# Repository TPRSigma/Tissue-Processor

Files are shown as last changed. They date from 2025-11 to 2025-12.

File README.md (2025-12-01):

# Tissue-Processor
Simple Tissue Processor for fixation and contrasting of samples for **light and electron microscopy**. 

Úvodní obr

This repository contains the documentation, control files, and construction details for a custom-built **automated tissue processor** designed for preparing biological samples for **light and electron microscopy**.  
The device automates sequential immersion of samples into up to **20 reagent baths**, following a user-defined protocol stored on an SD card.

---

## Key Features

- **Fully automated sample immersion** into up to 20 baths  
- **Compatible with Leica EM CPD300 baskets** (up to 4 baskets per run)  
- **Motorized carousel + lift** controlled by an onboard microcontroller  
- **e-mail notifications** (status, errors, power outage alerts)  
- **Backup battery** to complete the ongoing immersion step  
- **Simple protocol definition** via text file (`proto_NN.txt`) on SD card  
- **Manual control mode** for lift and carousel  
- **Intuitive front-panel interface** with MENU/ENTER buttons and rotary knob

---

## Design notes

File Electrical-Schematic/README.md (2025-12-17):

# Electrical Schematic – Tissue Processor

This directory contains the electrical schematics of the **Tissue Processor** device,
showing the interconnection of all electronic components.

The schematics document:
- power distribution and voltage regulation  
- microcontroller connections  
- motor drivers and actuators  
- sensors and limit switches  
- display, control panel, and user inputs  
- communication interfaces (Bluetooth, I²C, SPI)  

---

## 🖼️ Schematic Overview

<p align="center">
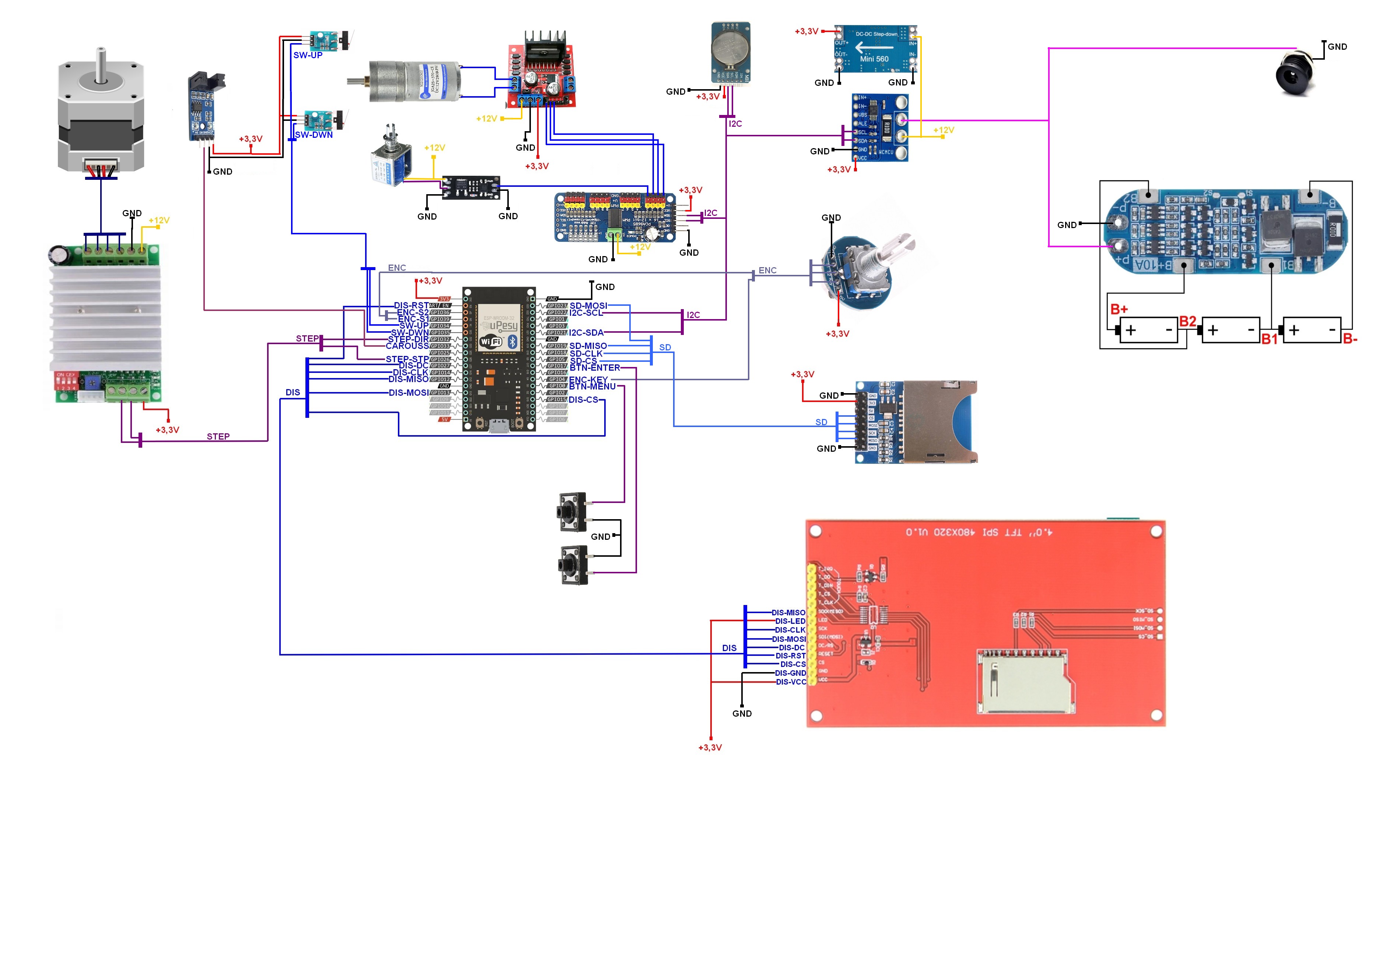
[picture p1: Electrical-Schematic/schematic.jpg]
Tissue Processor Electrical Schematic
  
</p>

---

The diagram provides an overview of the system architecture and wiring between
individual modules. It is intended as a reference for maintenance, debugging,
and further development.

> **Note:** Component values, pin assignments, and wiring correspond to the hardware
revision used in this project. Hardware changes may require schematic updates.

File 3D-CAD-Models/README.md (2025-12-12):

# 3D CAD Models
This directory contains **3D CAD models** of individual parts of the Tissue Processor in **STL** format as well as the entire assembly **TP-assembly** in **IGES** and **STEP** formats.
<br>
<p align="center">TP-assembly</p>

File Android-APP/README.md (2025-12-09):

# TP Control v1.0 – Android App for Tissue Processor

<p align="center">

</p>
<sup> © 2025 Jane Doe – Released under the MIT License.</sup>

<br>
<br>
    
This directory contains the Android application **TP Control**, which communicates 
with the Tissue Processor device via Bluetooth.

The app provides a user-friendly interface for:

- Connecting to the Tissue Processor via Bluetooth  
- Configuring device settings  
- Creating and editing tissue-processing protocols

---
## 📦 Structure
```
/Android-APP
│
├── build/ # Compiled APK
└── README.md
```
<!-- ├── app/ # Android Studio project -->
---

## 📲 Installing an APK on Android (build)

This guide explains how to install an Android application directly from an `.apk` file, without using the Google Play Store.

---

### 1. Enable Installation from Unknown Sources

1. Open **Settings** on your Android device.
2. Go to **Apps** or **Apps & notifications**.
3. Find **Special app access** or **Install unknown apps**.
4. Select the app you will use to install the APK (e.g., **Browser** or **File Manager**).
5. Enable **Allow from this source**.

> ⚠️ Warning: Installing apps from unknown sources can be a security risk. Only install trusted APKs.

---

### 2. Transfer the APK to Your Device

- Move the `.apk` file to your device via USB, email, cloud storage, or Bluetooth.
- Recommended location: **Downloads** folder or a folder you commonly use for files.

---

### 3. Open the APK File

1. Open a **File Manager** or **Downloads** app on your device.
2. Locate the `.apk` file you want to install.
3. Tap the file and confirm the installation.

---

### 4. Complete Installation

- Follow the installer prompts.
- Once finished, you can open the app directly or find it on your home screen.

---

### 5. Tips

- If the installation fails, make sure the `.apk` file is not corrupted and is compatible with your Android version.
- After installation, consider disabling **installation from unknown sources** for security.
---

### 6. Pair the app with the Tissue Processor over Bluetooth.
> **Note:** The app requires Bluetooth permission on the Android device.
---
<!--
## 📲 Installing and Running APP

1. Open the project in **Android Studio**.  
2. Connect an Android device or emulator.  
3. Build and run the app.  
4. Pair the app with the Tissue Processor over Bluetooth.

> **Note:** The app requires Bluetooth permission on the Android device.

---
-->

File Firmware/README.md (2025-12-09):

# Firmware v22.a
<p align="center">

</p>
<sup>© 2025 Jane Doe – Released under the MIT License.</sup>
<br>
<br>
This directory contains the firmware used to control the Tissue Processor device.  
It includes:

- **Main Arduino project** (`tissue_processor.ino`)  
  The primary source code for the microcontroller.  
- **Precompiled firmware binaries** (in the `/bin` subfolder)  
  These files can be flashed directly onto the device without rebuilding the project.

The firmware controls all key functions of the device, including:
- carousel rotation  
- lift motion  
- protocol execution  
- SD card management  
- display and control panel interface  
- error reporting and network notifications
- Bluetooth interface for communication with the Android companion app, which provides a user-friendly way to configure the device and create tissue-processing protocols.

---

## 📦 Structure
```
/Firmware
│
├── Graficke_rozhrani_v22a.ino        # Arduino IDE project
│
└── bin/
    ├── Graficke_rozhrani_v22a.ino.bin
    ├── Graficke_rozhrani_v22a.ino.elf
    └── ...
```
---

## 🛠️ Flashing the Firmware

To upload the firmware:

1. Open the `.ino` file in **Arduino IDE** (or PlatformIO).  
2. Select the correct board and COM port.  
3. Click **Upload**.

Or, to flash the precompiled binary using `esptool.py`:

```bash
esptool.py --chip esp32 write_flash 0x10000 Graficke_rozhrani_v22a.ino.merged.bin

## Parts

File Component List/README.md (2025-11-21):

# Bill of Materials (BOM)

## Electronics

| Qty | Component | Link |
|-----|---|---|
| 1 | Processor (ESP-32S) | https://www.laskakit.cz/iot-esp-32s-2-4ghz-dual-mode-wifi-bluetooth-rev-1--cp2102/ |
| 1 | Display (ST7796) | https://www.laskakit.cz/4-0--480x320-tft-displej--st7796--spi--dotykovy/ |
| 1 | Balancer / Charger (3S) | https://www.laskakit.cz/ochrana-li-ion-baterie-3s-10a/ |
| 1 | Stepdown 3.3V | https://www.laskakit.cz/mini-smd-step-down-menic-3-3v/ |
| 3 | Battery 18650 | https://www.laskakit.cz/geb-li-ion-baterie-18650-2200mah-3-7v/ |
| 1 | Battery Case (3×18650) | https://www.laskakit.cz/bateriovy-box-3x18650-dratove-vyvody/ |
| 1 | Photoelectric Gate | https://www.laskakit.cz/fotoelektricky-snimac-otacek/ |
| 1 | Stepper Motor (NEMA17) | https://www.laskakit.cz/krokovy-motor-nema-17-17hs2408-0-12nm/ |
| 1 | Cable for Stepper | https://www.laskakit.cz/kabel-pro-krokovy-motor-nema17-s-konektorem-jst-xh-1m/ |
| 1 | Stepper Motor Driver (TB6600) | https://www.laskakit.cz/driver-tb6600-pro-krokove-motory-4a-9-42v-pcb/ |
| 1 | DC Motor – 150 RPM | https://www.laskakit.cz/motor-jga25-370-12v-s-prevodovkou-/ |
| 1 | DC Driver (L298N) | https://www.laskakit.cz/h-mustek-pro-krokovy-motor-l298n--dualni-motorovy-modul/ |
| 1 | I2C PWM Driver (PCA9685) | https://www.laskakit.cz/16-kanalovy-12-bit-pwm-servo-mini-shield-i2c-pca9685/ |
| 1 | RTC DS3231 | https://www.laskakit.cz/rtc-hodiny-realneho-casu-ds3231--integrovana-baterie/ |
| 1 | PWM Module for Electromagnet | https://www.laskakit.cz/pwm-mosfet-modul-lr7843--30vdc-161a/ |
| 2 | Momentary Switch + Button | https://www.laskakit.cz/mikrospinac-tc-1212t-12x12x7-3mm/ ; https://www.laskakit.cz/tlacitko-12x12x7-3mm-s-knoflikem/?variantId=5051 |
| 1 | Rotary Encoder | https://www.laskakit.cz/rotacni-encoder-s-tlacitkem-a-rc-s-filtrem/ |
| 1 | Power Connector DC 5.5×2.1mm | https://www.laskakit.cz/napajeci-konektor-dc-022-5-5-2-1mm-do-panelu/ |
| 1 | Voltmeter Module | https://www.laskakit.cz/laskakit-ina226-sensor-pro-mereni-napeti--proudu-a-vykonu/ |
| 1 | Cable JST-SH 6-pin | https://www.laskakit.cz/--sup-spi-jst-sh-6-pin-kabel-dupont-samec/ |
| 1 | SD Card Reader | https://www.laskakit.cz/sd-card-modul-spi/ |
| 1 | Switch | https://www.laskakit.cz/spinac-kovovy-s-aretaci-power--stribrny-16mm-3-6v/ |
| 1 | AC Power Adapter 12V 3A | https://www.laskakit.cz/sitovy-napajeci-adapter-12v-3a-5-5-2-1mm/ |

## Mechanics / Construction

| Qty | Component | Link |
|-----|---|---|
| 1 | Threaded Rod 200 mm | https://dratek.cz/arduino/148409-zavitova-tyc-trapezova-t8-8-p2-pravy-zavit-s-matici-200mm.html |
| 1 | Shaft Coupling 5×8 mm | https://dratek.cz/arduino/122878-hridelova-spojka-pruzna-cnc-5x8mm.html |
| 1 | Bearing KP08 | https://dratek.cz/arduino/122932-kp08-upinaci-lozisko-8mm-stojate.html |
| 1 | Guide Rod 8 mm / 200 mm | https://dratek.cz/arduino/148608-vodici-tyc-ocelova-chromovana-prumer-8-mm-delka-200-mm.html |
| 1 | Linear Ball Bearing SC8UU | https://dratek.cz/arduino/7780-linearni-vozik-sc8uu.html |
| 2 | Limit Switch | https://www.laskakit.cz/koncovy-doraz-spinac--2a-125vac/ |
| 1 | Electromagnet | https://www.laskakit.cz/elektromagnet-tazny--12v-10mm-20n/ |
| 1 | Carousel Bearing Ø200 mm | https://www.kovaninabytkove.cz/p/otocny-mechanismus-pro-talir-desku-pr-200mm-1 |
| 20  | Centrifugal Glass Tubes 25 ml (H095003)  | https://www.p-lab.cz/zkumavka-centrifugacni-s-kulatym-dnem |

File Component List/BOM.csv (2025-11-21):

Category | Qty | Component | Link
Electronics | 1 | Processor (ESP-32S) | https://www.laskakit.cz/iot-esp-32s-2-4ghz-dual-mode-wifi-bluetooth-rev-1--cp2102/
Electronics | 1 | Display (ST7796) | https://www.laskakit.cz/4-0--480x320-tft-displej--st7796--spi--dotykovy/
Electronics | 1 | Balancer / Charger (3S) | https://www.laskakit.cz/ochrana-li-ion-baterie-3s-10a/
Electronics | 1 | Stepdown 3.3V | https://www.laskakit.cz/mini-smd-step-down-menic-3-3v/
Electronics | 3 | Battery 18650 | https://www.laskakit.cz/geb-li-ion-baterie-18650-2200mah-3-7v/
Electronics | 1 | Battery Case (3×18650) | https://www.laskakit.cz/bateriovy-box-3x18650-dratove-vyvody/
Electronics | 1 | Photoelectric Gate | https://www.laskakit.cz/fotoelektricky-snimac-otacek/
Electronics | 1 | Stepper Motor (NEMA17) | https://www.laskakit.cz/krokovy-motor-nema-17-17hs2408-0-12nm/
Electronics | 1 | Cable for Stepper | https://www.laskakit.cz/kabel-pro-krokovy-motor-nema17-s-konektorem-jst-xh-1m/
Electronics | 1 | Stepper Motor Driver (TB6600) | https://www.laskakit.cz/driver-tb6600-pro-krokove-motory-4a-9-42v-pcb/
Electronics | 1 | DC Motor – 150 RPM | https://www.laskakit.cz/motor-jga25-370-12v-s-prevodovkou-/
Electronics | 1 | DC Driver (L298N) | https://www.laskakit.cz/h-mustek-pro-krokovy-motor-l298n--dualni-motorovy-modul/
Electronics | 1 | I2C PWM Driver (PCA9685) | https://www.laskakit.cz/16-kanalovy-12-bit-pwm-servo-mini-shield-i2c-pca9685/
Electronics | 1 | RTC DS3231 | https://www.laskakit.cz/rtc-hodiny-realneho-casu-ds3231--integrovana-baterie/
Electronics | 1 | PWM Module for Electromagnet | https://www.laskakit.cz/pwm-mosfet-modul-lr7843--30vdc-161a/
Electronics | 2 | Momentary Switch + Button | https://www.laskakit.cz/mikrospinac-tc-1212t-12x12x7-3mm/ ; https://www.laskakit.cz/tlacitko-12x12x7-3mm-s-knoflikem/?variantId=5051
Electronics | 1 | Rotary Encoder | https://www.laskakit.cz/rotacni-encoder-s-tlacitkem-a-rc-s-filtrem/
Electronics | 1 | Power Connector DC 5.5×2.1mm | https://www.laskakit.cz/napajeci-konektor-dc-022-5-5-2-1mm-do-panelu/
Electronics | 1 | Voltmeter Module | https://www.laskakit.cz/laskakit-ina226-sensor-pro-mereni-napeti--proudu-a-vykonu/
Electronics | 1 | Cable JST-SH 6-pin | https://www.laskakit.cz/--sup-spi-jst-sh-6-pin-kabel-dupont-samec/
Electronics | 1 | SD Card Reader | https://www.laskakit.cz/sd-card-modul-spi/
Electronics | 1 | Switch | https://www.laskakit.cz/spinac-kovovy-s-aretaci-power--stribrny-16mm-3-6v/
Electronics | 1 | AC Power Adapter 12V 3A | https://www.laskakit.cz/sitovy-napajeci-adapter-12v-3a-5-5-2-1mm/
Mechanics | 1 | Threaded Rod 200 mm | https://dratek.cz/arduino/148409-zavitova-tyc-trapezova-t8-8-p2-pravy-zavit-s-matici-200mm.html
Mechanics | 1 | Shaft Coupling 5×8 mm | https://dratek.cz/arduino/122878-hridelova-spojka-pruzna-cnc-5x8mm.html
Mechanics | 1 | Bearing KP08 | https://dratek.cz/arduino/122932-kp08-upinaci-lozisko-8mm-stojate.html
Mechanics | 1 | Guide Rod 8 mm / 200 mm | https://dratek.cz/arduino/148608-vodici-tyc-ocelova-chromovana-prumer-8-mm-delka-200-mm.html
Mechanics | 1 | Linear Ball Bearing SC8UU | https://dratek.cz/arduino/7780-linearni-vozik-sc8uu.html
Mechanics | 2 | Limit Switch | https://www.laskakit.cz/koncovy-doraz-spinac--2a-125vac/
Mechanics | 1 | Electromagnet | https://www.laskakit.cz/elektromagnet-tazny--12v-10mm-20n/
Mechanics | 1 | Carousel Bearing O200 mm | https://www.kovaninabytkove.cz/p/otocny-mechanismus-pro-talir-desku-pr-200mm-1
Mechanics | 20 | Centrifugal Glass Tubes 25 ml (H095003) | https://www.p-lab.cz/zkumavka-centrifugacni-s-kulatym-dnem

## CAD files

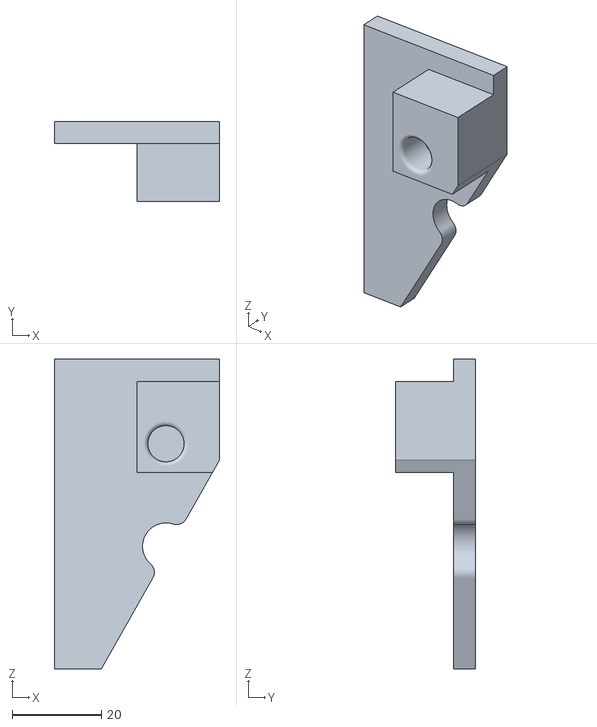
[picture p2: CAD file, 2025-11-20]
3D-CAD-Models/Rod Cover (Krytka tyče).stl
37.0 x 18.0 x 69.5

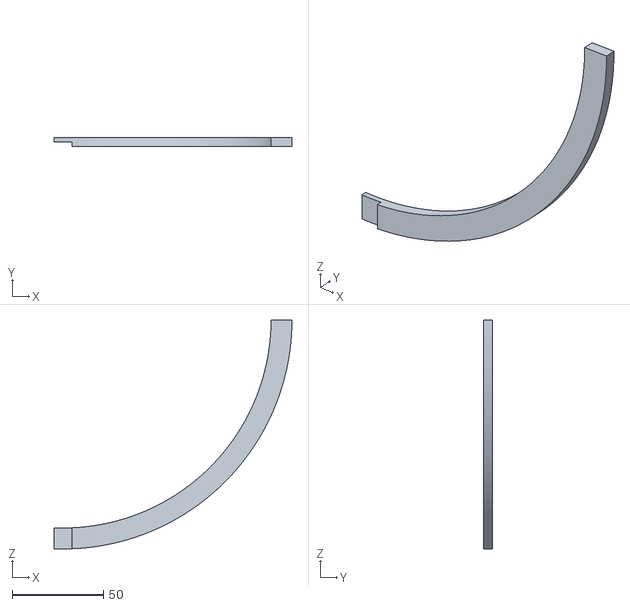
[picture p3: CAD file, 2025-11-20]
3D-CAD-Models/Top Back Plate 2 (Vrchni deska Zadní2).stl
130.6 x 5.00 x 125.6

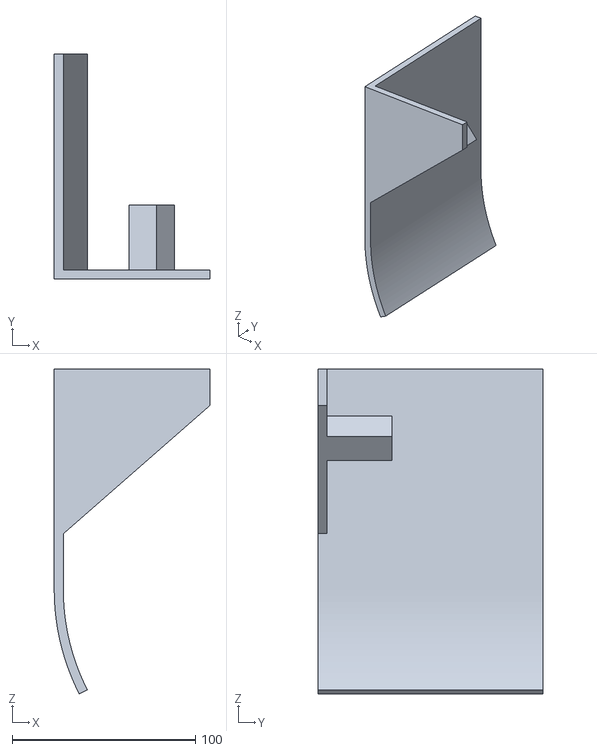
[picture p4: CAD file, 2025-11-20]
3D-CAD-Models/Right Panel 1 (Panel boční R_1).stl
85.0 x 123.0 x 177.6

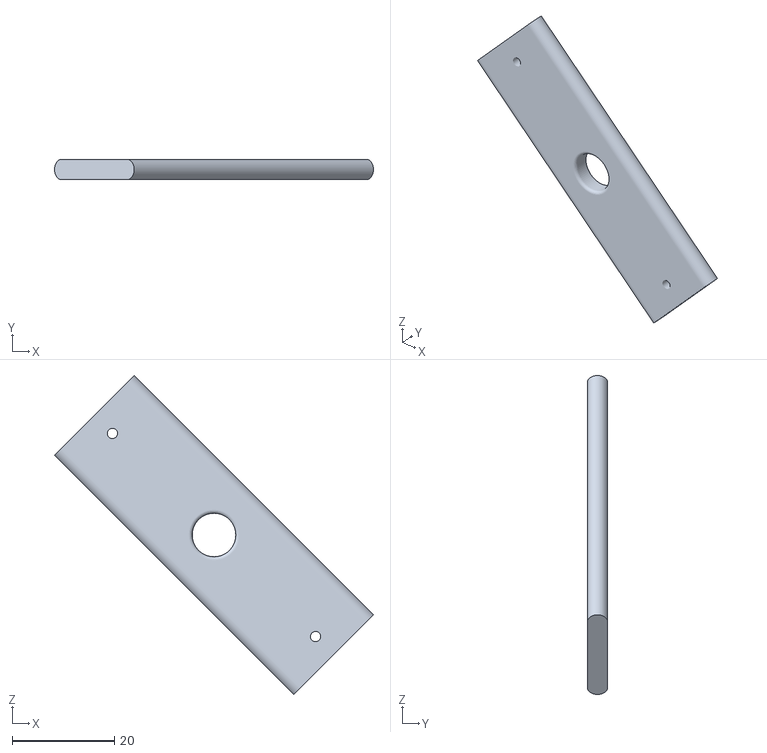
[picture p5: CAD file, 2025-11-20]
3D-CAD-Models/Sliding Bar (Posuvná lišta).stl
62.3 x 4.00 x 62.3

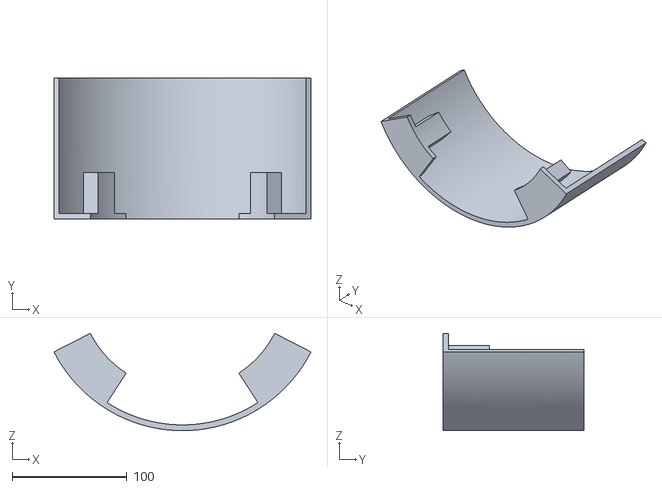
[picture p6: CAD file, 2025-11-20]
3D-CAD-Models/Rear Panel (Panel zadní).stl
223.7 x 123.0 x 84.7

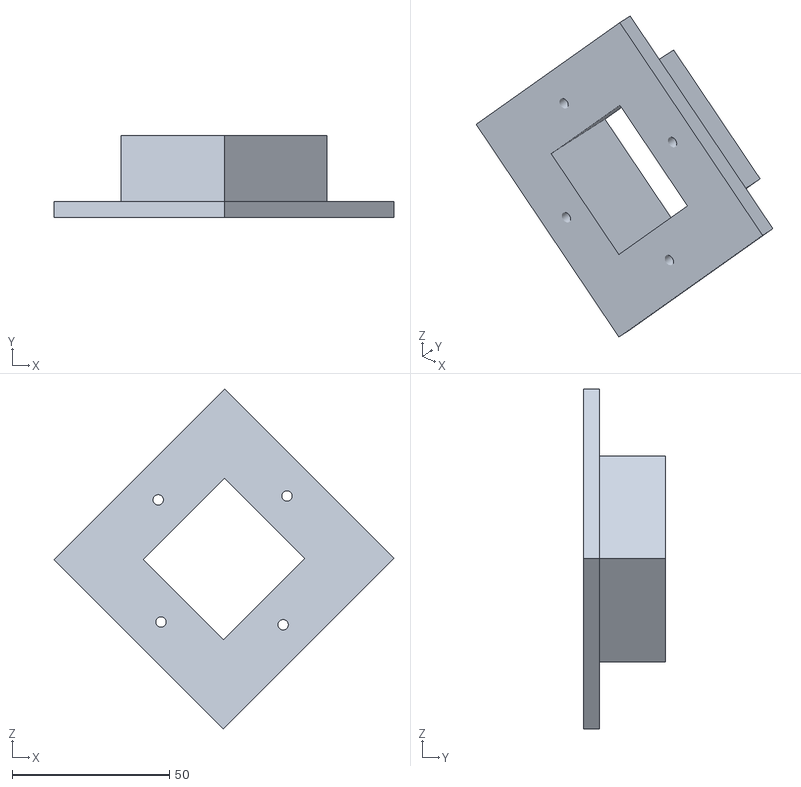
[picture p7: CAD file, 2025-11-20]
3D-CAD-Models/Lid Housing (Domeček víka).stl
108.0 x 26.0 x 108.0

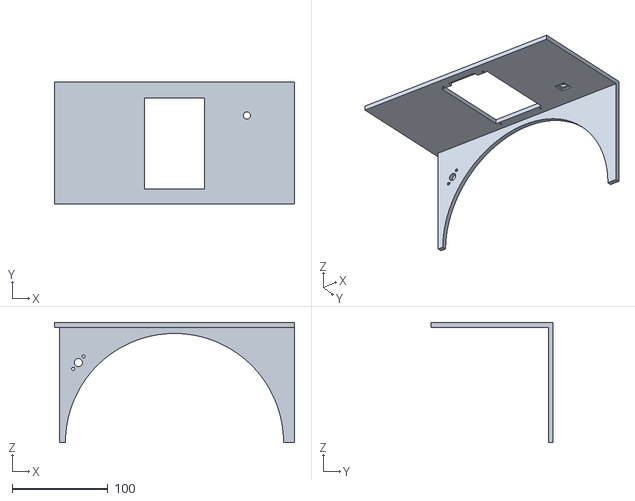
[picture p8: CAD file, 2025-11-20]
3D-CAD-Models/Front Panel (Panel přední).stl
251.1 x 128.0 x 125.6

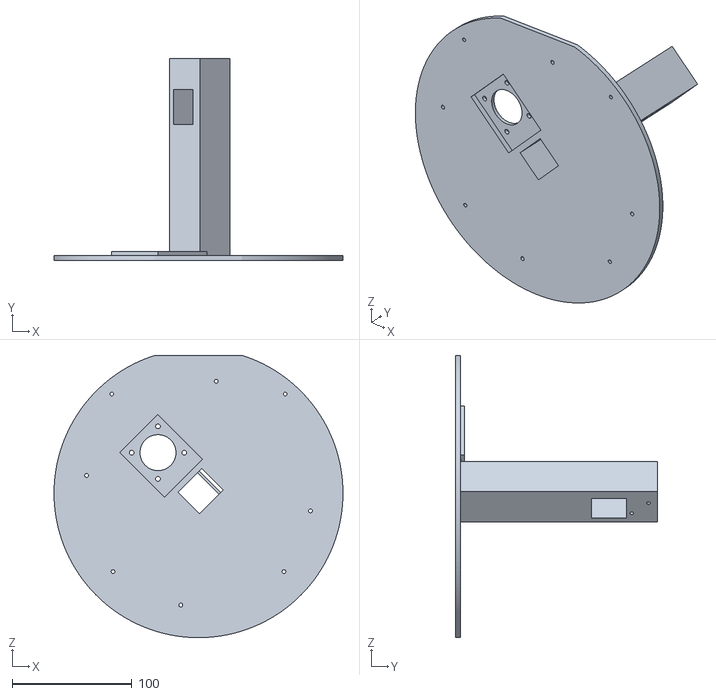
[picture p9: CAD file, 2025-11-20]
3D-CAD-Models/Base (Podstavec).stl
241.1 x 168.5 x 235.5

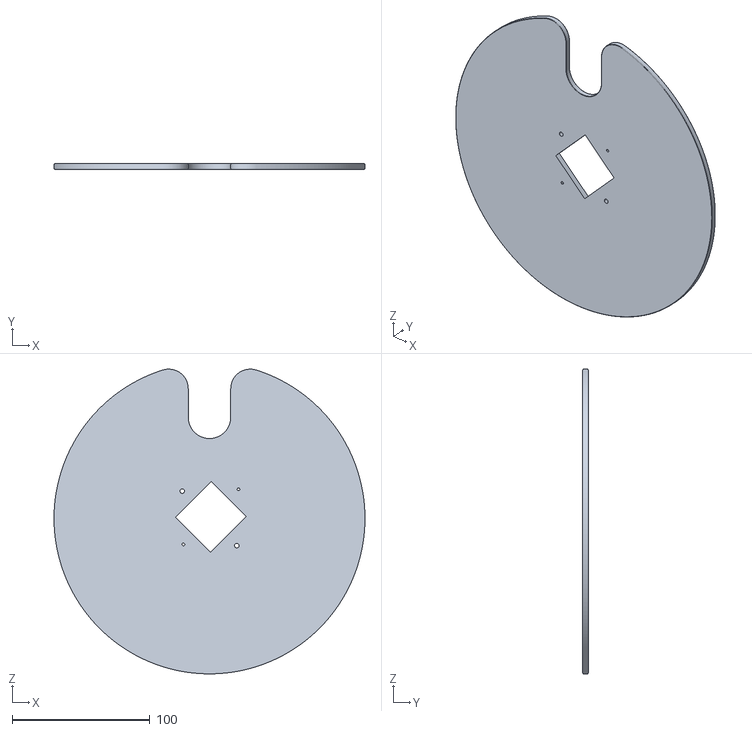
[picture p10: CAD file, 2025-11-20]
3D-CAD-Models/Lid (Víko).stl
226.1 x 4.00 x 221.6

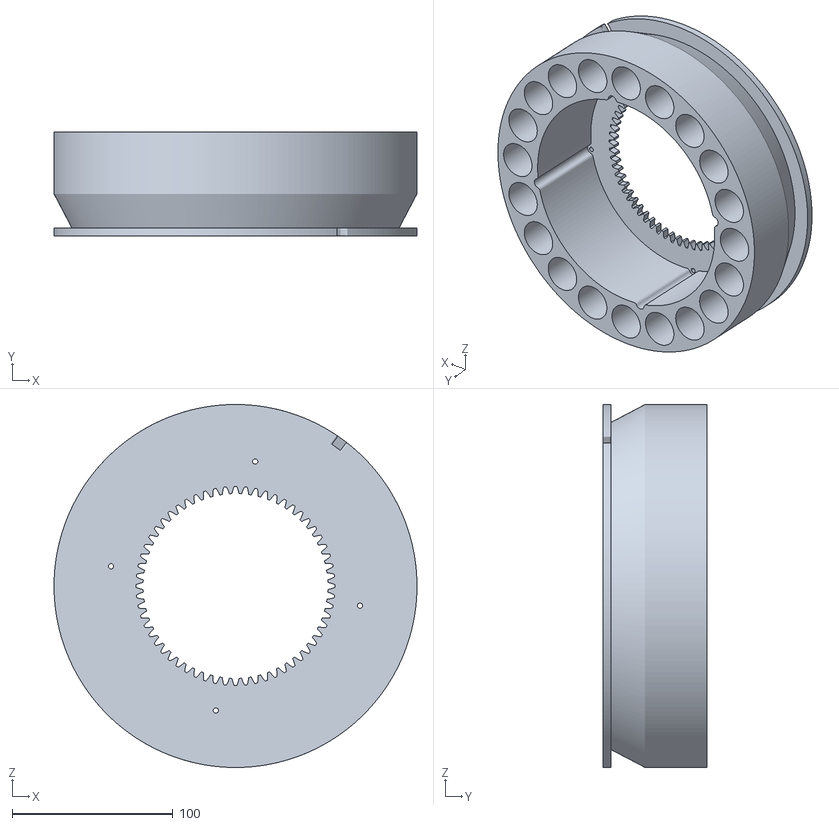
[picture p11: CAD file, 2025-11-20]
3D-CAD-Models/Carousel (Karusel).stl
226.1 x 65.0 x 226.1

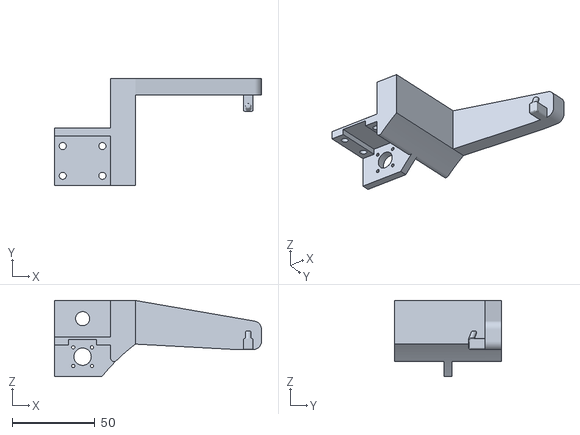
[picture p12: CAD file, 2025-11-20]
3D-CAD-Models/Holder (Držák).stl
125.3 x 65.0 x 46.0

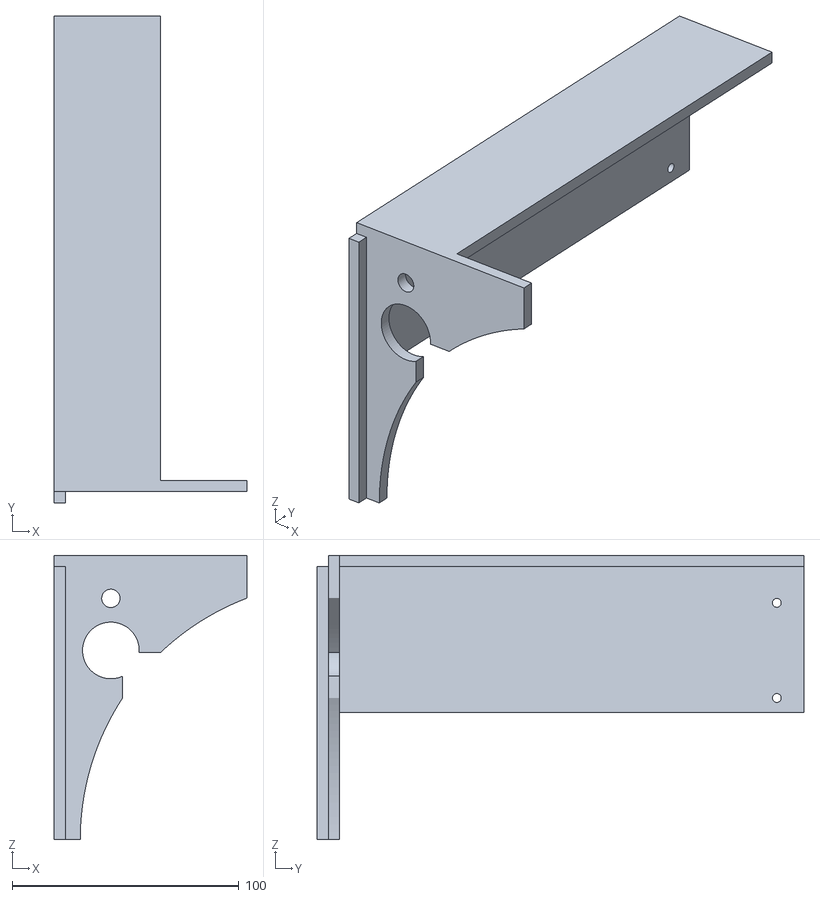
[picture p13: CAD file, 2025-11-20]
3D-CAD-Models/Right Panel 2 (Panel boční R_2).stl
85.0 x 215.0 x 125.6

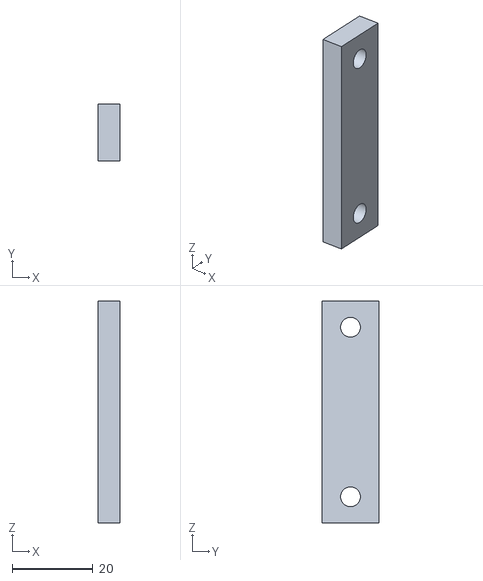
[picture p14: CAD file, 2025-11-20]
3D-CAD-Models/Bearing Base (podstava ložiska tyčky).stl
5.50 x 14.0 x 55.0

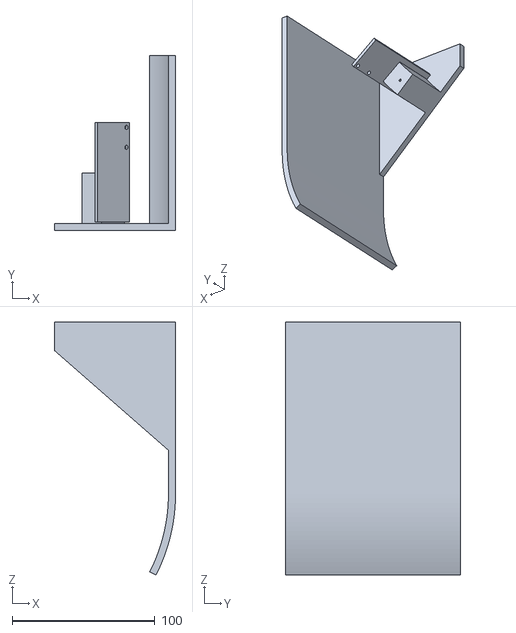
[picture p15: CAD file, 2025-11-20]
3D-CAD-Models/Left Panel (Panel boční L).stl
85.0 x 123.0 x 177.6

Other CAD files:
3D-CAD-Models/Top Back Plate 1 (Vrchni deska Zadní-1).stl

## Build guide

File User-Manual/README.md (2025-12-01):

# Tissue Processor - Quick Start Guide
Manuál

---
### 1. Prepare the SD Card
Create or copy the following files to the SD card:

- **proto_XX.txt** protocol file that defines immersion steps
- **config.txt** device configuration (network, timings, etc.)
- **log.txt** created and updated automatically

**Protocol files must follow the format:**
proto_01.txt ... proto_99.txt

Each protocol contains:
- 3 comment lines  
- 20× (bath name + duration in seconds)

---

### 2. Fill the Reagent Baths
1. Turn on the device (230 V AC).  
2. Insert the SD card on the left side of the device.  
3. Navigate to **FILL** using the `MENU` button.  
4. Press **ENTER** → carousel rotates to bath 1.  
5. Fill using a pipette.  
6. Press **ENTER** again to move to bath 2.  
7. Repeat for all baths.

Recommended volumes (for 4 baskets):  
- **Bath 1:** 12 ml  
- **Baths 2–20:** 10 ml each  

---

### 3. Load the Sample Baskets
- Insert up to **4 baskets** (Leica-compatible) into the holder.  
- Suspend the holder on the motorized lift.

---

### 4. Run the Immersion Process
1. Navigate to **STAT** and press **ENTER**.  
2. Confirm the selected protocol.  
3. The processor begins immersing samples according to the timing in the protocol.

Displayed status includes:
- current bath  
- remaining time  
- power/battery state  
- network status  
- selected protocol file  
- overall process state

---

### 5. Manual Control (Optional)
Under **RUN** tab:
- **Lift UP / Down**  
- **Carousel zero**  
- **Carousel 1 FWD / BCW**  
- **STOP / ZERO position**

---

### 6. After Processing
- Remove and clean all tubes.  
- Turn off the device by disconnecting power.

---

## Full User Manual

**The complete detailed manual** (purpose, description, interface, protocol format, operation, etc.) is in the **manual.md** and/or **manual.pdf** files in this ("User-Manual") repository folder.

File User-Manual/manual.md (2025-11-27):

# Tissue Processor – User Manual

## Purpose of the Tissue Processor

The purpose of this tissue processor is to automate part of the preparation of biological samples prior to imaging in a scanning electron microscope (SEM). Samples intended for SEM must undergo several preparation steps. They are typically cleaned, trimmed to the required size, and—in the case of biological tissues—subjected to more complex preparation.

No sample containing moisture may enter the vacuum chamber of an electron microscope. Any remaining liquid may cause the sample to explode, potentially damaging delicate detectors. Biological tissues also degrade rapidly, leading to changes in structure and composition. Once dried, the samples become non-conductive and accumulate charge under the electron beam, which reduces image quality.

Therefore, biological tissue samples must be fixed, dehydrated, and later coated with a conductive layer. Fixation and dehydration consist of a series of immersions in suitable liquids, such as various concentrations of ethanol, formaldehyde, or distilled water for rinsing. Performing these immersions manually is monotonous, time-consuming, and prone to errors. The tissue processor automates this sequence.

Although the device is designed for preparing biological samples for SEM imaging, it can also be used for other laboratory procedures that require sequential immersion in multiple baths.

---

## Description of the Tissue Processor

The basic principle of the tissue processor is shown in the schematic diagram in **Fig. 1**, and the finished device is shown in **Fig. 2**. The core of the device is a rotating carousel with 20 openings for glass tubes. Each tube is 100 mm tall and 24 mm in outer diameter and serves as a bath for sample immersion.

These dimensions allow inserting a stack of **four sample baskets**, each containing biological material. These baskets are compatible with the Leica EM CPD300 device and have an outer diameter of 16 mm and a height of 11 mm. The baskets are held in a frame suspended from a motorized lift positioned at the edge of the carousel. The lift, controlled by software, lowers the basket assembly into the tube and raises it again. A detail of this basket assembly is shown in **Fig. 3**.

TP-assembly

**Fig. 1 –** Overview schematic of the tissue processor with front panel, carousel, lift mechanism, and protective lid.  

PB250017

**Fig. 2 –** Overall view of the manufactured tissue processor with tubes and sample baskets.  



**Fig. 3 –** Detail of the basket assembly suspended on the lift above the baths.

---

The synchronized motion of the carousel and the lift allows samples to be immersed in different liquids placed in the tubes. A lid covers the baths; it has an opening aligned only with the lift so that the holder can be lowered into the selected tube. The lid prevents evaporation and protects the baths that are not currently in use. During carousel rotation, the lid slightly lifts.

The tissue processor is equipped with network connectivity. It can send SMS notifications about the progress of immersion steps, including error messages or detection of a power outage. In such an event, an internal backup battery ensures that the device can complete the current immersion step and send a warning message.

---

## Protocol

In this context, a *protocol* defines the precise sequence of steps required to prepare the samples—specifically, immersing them in different baths for predetermined times.

The current software rotates the carousel in only one direction, meaning that the samples are immersed sequentially from bath 1 onward.

Protocols are stored as text files on an SD card inserted on the left side of the device. The file name must follow the format:

**proto_NN.txt**  
where **NN** is a number from 01 to 99.

Each protocol file describes the immersion time in each bath. An example of such a control file is shown in **Fig. 4**.  
The first three lines contain comments. The remainder consists of 20 pairs of lines:

- the first line of each pair: name of the bath (matching its contents),  
- the second line: immersion time in seconds.

Future versions of the software may include additional parameters controlling lift movement.

VypisSouboru

**Fig. 4 –** Example of a control file defining the immersion protocol.

---

## Operating the Device

The control panel is located on the front side of the device (see **Fig. 5**). On the left are two buttons, **ENTER** and **MENU**; in the center is a narrow display; and on the right is a rotary knob used for vertical navigation in the menu. Before switching between menu items, the rotary knob must be pressed, similar to a button.

On the left side of the device is the SD card slot. The SD card must contain:

- the protocol control file,  
- the configuration file **config.txt**,  
- the log file **log.txt**.

The device starts when it is connected to a 230 V AC mains power supply. Operating the device consists of two main phases:  
1. filling the baths (tubes) with the required liquids,  
2. running the immersion program.


**Fig. 5 –** Front panel of the tissue processor showing the display with menu and tabs.

---

After turning the device on, the screen displays a menu with five tabs:

- **STAT** – starts the immersion process; shows the status of the process  
- **RUN** – allows manual movements of the carousel and lift  
- **PROG** – selects the protocol file  
- **FILL** – used for filling the baths  
- **SET** – displays configuration settings from config.txt  

Pressing the MENU button cycles through the tabs. Pressing ENTER activates a command or confirms a selection.

---

### Filling the baths

Filling the baths with liquids is an essential step before immersion begins. The device can accommodate up to 20 different baths containing solutions for fixation, rinsing, or dehydration, arranged in the order defined by the protocol.

It is assumed that the liquids are added shortly before the immersion process begins and removed afterward. If the basket holder contains all four baskets, the recommended volumes are:

- **12 ml** for bath 1  
- **10 ml** for each subsequent bath  

To fill the baths, navigate to the **FILL** tab and press ENTER. The carousel rotates to position bath 1 under the opening in the lid. Fill it using a pipette. Press ENTER again to rotate to bath 2, and continue until all baths are filled.

---

### Running the immersion process

Once all baths are filled and the basket holder is suspended on the lift, the immersion process may begin. Navigate to the **STAT** tab and press ENTER. After confirmation, the program immerses the samples in the baths according to the protocol.

The bottom part of the display shows:

- the protocol filename  
- the name of the current bath  
- the remaining time for the immersion  

The upper part of the STAT tab displays:

- current date and time  
- **Power:** whether the device is running on mains power or battery  
- **Battery:** battery status  
- **Network:** the network ID the device is connected to  
- **Protocol:** active protocol filename  
- **Status:** current stage of the immersion sequence (or *to start program* if idle)

---

### Manual control (RUN tab)

In the **RUN** tab, simple manual operations can be performed:

- **Lift UP** – lift the samples out of the bath  
- **Lift DWN** – lower the samples into the bath  
- **Carousel zero** – rotate to the defined starting position  
- **Carousel 1 FWD** – rotate forward by one position  
- **Carousel 1 BCW** – rotate backward by one position  
- **STOP** – immediately stop the running process  
- **ZERO position** – stop and rotate to the starting position without lifting samples  

Carousel movements can be used to sequentially position each tube under the lid, allowing easy removal and cleaning.

The tissue processor is switched off by disconnecting the power supply.

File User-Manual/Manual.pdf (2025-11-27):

# Tissue Processor – User Manual

## Purpose of the Tissue Processor

The purpose of this tissue processor is to automate part of the preparation of biological samples prior to imaging in a scanning electron microscope (SEM). Samples intended for SEM must undergo several preparation steps. They are typically cleaned, trimmed to the required size, and—in the case of biological tissues—subjected to more complex preparation.

No sample containing moisture may enter the vacuum chamber of an electron microscope. Any remaining liquid may cause the sample to explode, potentially damaging delicate detectors. Biological tissues also degrade rapidly, leading to changes in structure and composition. Once dried, the samples become non-conductive and accumulate charge under the electron beam, which reduces image quality.

Therefore, biological tissue samples must be fixed, dehydrated, and later coated with a conductive layer. Fixation and dehydration consist of a series of immersions in suitable liquids, such as various concentrations of ethanol, formaldehyde, or distilled water for rinsing. Performing these immersions manually is monotonous, time-consuming, and prone to errors. The tissue processor automates this sequence.

Although the device is designed for preparing biological samples for SEM imaging, it can also be used for other laboratory procedures that require sequential immersion in multiple baths.

## Description of the Tissue Processor

The basic principle of the tissue processor is shown in the schematic diagram in Fig. 1, and the finished device is shown in Fig. 2. The core of the device is a rotating carousel with 20 openings for glass tubes. Each tube is 100 mm tall and 24 mm in outer diameter and serves as a bath for sample immersion.

These dimensions allow inserting a stack of four sample baskets, each containing biological material. These baskets are compatible with the Leica EM CPD300 device and have an outer diameter of 16 mm and a height of 11 mm. The baskets are held in a frame suspended from a motorized lift positioned at the edge of the carousel. The lift, controlled by software, lowers the basket assembly into the tube and raises it again. A detail of this basket assembly is shown in Fig. 3.

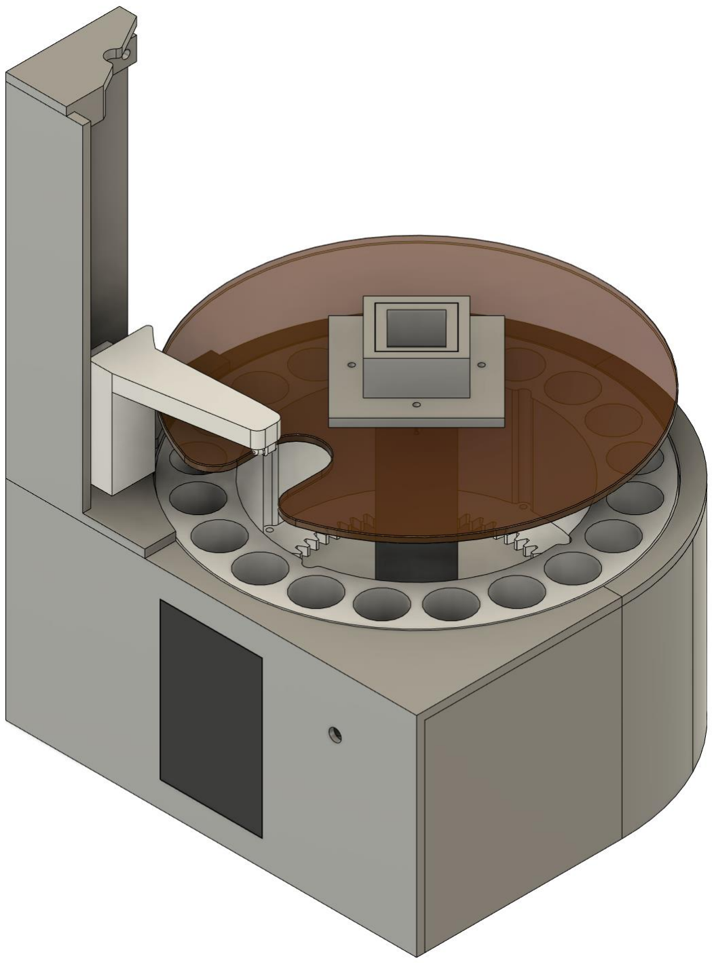
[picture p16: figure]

Fig. 1 – Overview schematic of the tissue processor with front panel, carousel, lift mechanism, and protective lid.

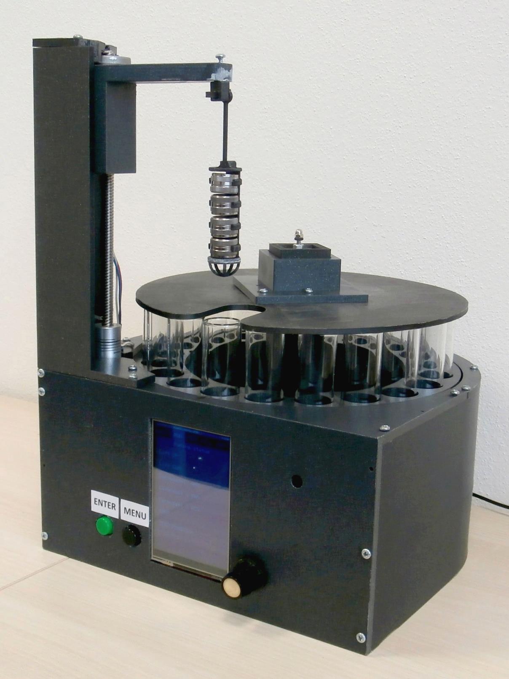
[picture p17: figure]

Fig. 2 – Overall view of the manufactured tissue processor with tubes and sample baskets.

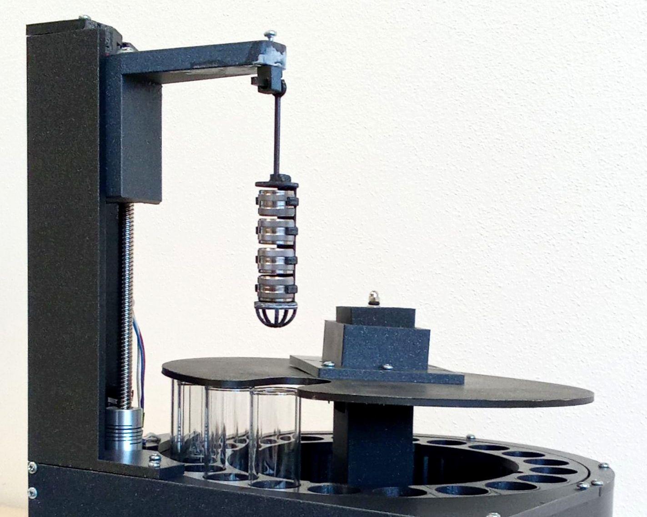
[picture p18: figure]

Fig. 3 – Detail of the basket assembly suspended on the lift above the baths.

The synchronized motion of the carousel and the lift allows samples to be immersed in different liquids placed in the tubes. A lid covers the baths; it has an opening aligned only with the lift so that the holder can be lowered into the selected tube. The lid prevents evaporation and protects the baths that are not currently in use. During carousel rotation, the lid slightly lifts.

The tissue processor is equipped with network connectivity. It can send SMS notifications about the progress of immersion steps, including error messages or detection of a power outage. In such an event, an internal backup battery ensures that the device can complete the current immersion step and send a warning message.

## Protocol

In this context, a protocol defines the precise sequence of steps required to prepare the samples—specifically, immersing them in different baths for predetermined times.

The current software rotates the carousel in only one direction, meaning that the samples are immersed sequentially from bath 1 onward.

Protocols are stored as text files on an SD card inserted on the left side of the device. The file name must follow the format:

proto_NN.txt
where NN is a number from 01 to 99.

Each protocol file describes the immersion time in each bath. An example of such a control file is shown in Fig. 4.
The first three lines contain comments. The remainder consists of 20 pairs of lines:
- the first line of each pair: name of the bath (matching its contents),
- the second line: immersion time in seconds.

Future versions of the software may include additional parameters controlling lift movement.

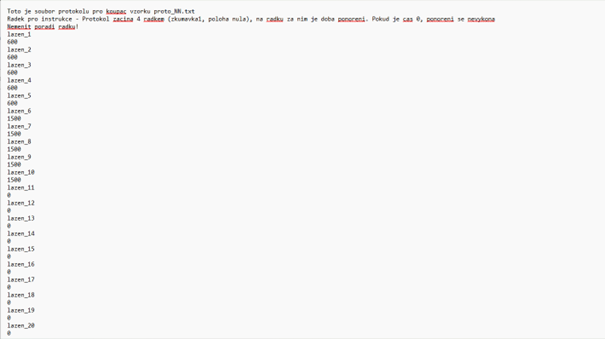
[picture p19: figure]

Fig. 4 – Example of a control file defining the immersion protocol.

## Operating the Device

The control panel is located on the front side of the device (see Fig. 5). On the left are two buttons, ENTER and MENU; in the center is a narrow display; and on the right is a rotary knob used for vertical navigation in the menu. Before switching between menu items, the rotary knob must be pressed, similar to a button.

On the left side of the device is the SD card slot. The SD card must contain:

- the protocol control file,
- the configuration file config.txt,
- the log file log.txt.

The device starts when it is connected to a 230 V AC mains power supply. Operating the device consists of two main phases:

1. filling the baths (tubes) with the required liquids,
2. running the immersion program.

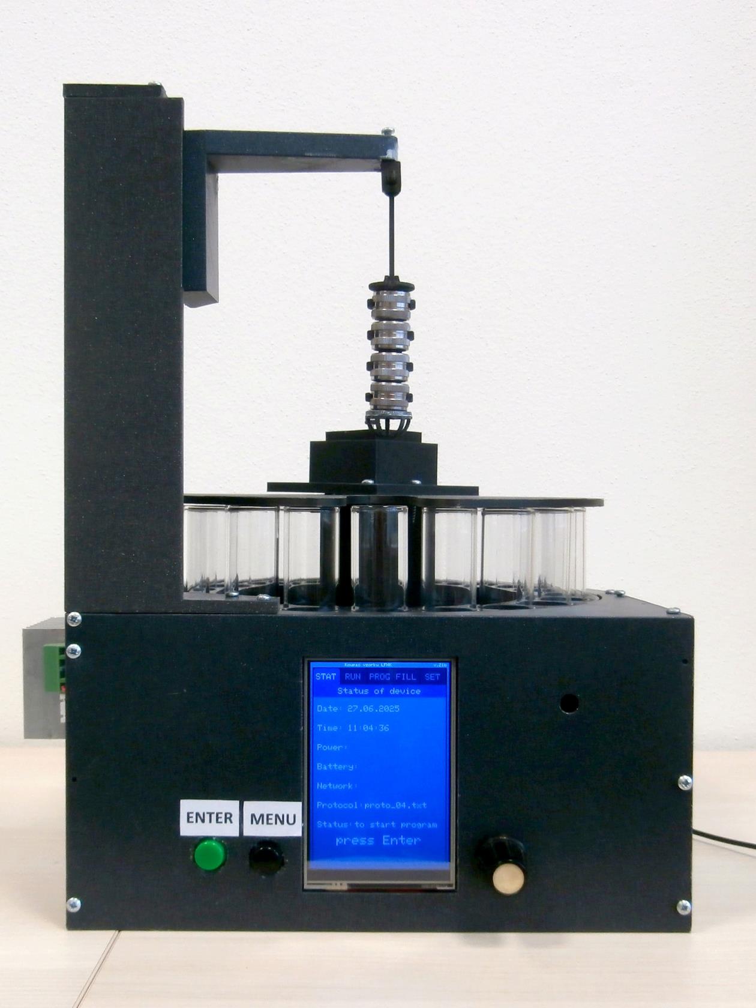
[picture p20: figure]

Fig. 5 – Front panel of the tissue processor showing the display with menu and tabs.

After turning the device on, the screen displays a menu with five tabs:

- STAT – starts the immersion process; shows the status of the process
- RUN – allows manual movements of the carousel and lift
- PROG – selects the protocol file
- FILL – used for filling the baths
- SET – displays configuration settings from config.txt

Pressing the MENU button cycles through the tabs. Pressing ENTER activates a command or confirms a selection.

Filling the baths

Filling the baths with liquids is an essential step before immersion begins. The device can accommodate up to 20 different baths containing solutions for fixation, rinsing, or dehydration, arranged in the order defined by the protocol.

It is assumed that the liquids are added shortly before the immersion process begins and removed afterward. If the basket holder contains all four baskets, the recommended volumes are:

- 12 ml for bath 1
- 10 ml for each subsequent bath

To fill the baths, navigate to the FILL tab and press ENTER. The carousel rotates to position bath 1 under the opening in the lid. Fill it using a pipette. Press ENTER again to rotate to bath 2, and continue until all baths are filled.

Running the immersion process

Once all baths are filled and the basket holder is suspended on the lift, the immersion process may begin. Navigate to the STAT tab and press ENTER. After confirmation, the program immerses the samples in the baths according to the protocol.

The bottom part of the display shows:

- the protocol filename
- the name of the current bath
- the remaining time for the immersion

The upper part of the STAT tab displays:

- current date and time
- Power: whether the device is running on mains power or battery

- Battery: battery status
- Network: the network ID the device is connected to
- Protocol: active protocol filename
- Status: current stage of the immersion sequence (or to start program if idle)

Manual control (RUN tab)

In the RUN tab, simple manual operations can be performed:

- Lift UP – lift the samples out of the bath
- Lift DWN – lower the samples into the bath
- Carousel zero – rotate to the defined starting position
- Carousel 1 FWD – rotate forward by one position
- Carousel 1 BCW – rotate backward by one position
- STOP – immediately stop the running process
- ZERO position – stop and rotate to the starting position without lifting samples

Carousel movements can be used to sequentially position each tube under the lid, allowing easy removal and cleaning.

The tissue processor is switched off by disconnecting the power supply.

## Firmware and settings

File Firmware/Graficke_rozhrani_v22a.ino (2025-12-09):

/*
Koupač vzorků - verze 21b logování a trochu úklid
*/

#include "SPI.h"
#include "TFT_eSPI.h"
#include "Wire.h"
#include "RTClib.h"
#include "FS.h"
#include "SD.h"
#include <Adafruit_PWMServoDriver.h>
#include <Wire.h>
#include <AccelStepper.h>
 
TFT_eSPI tft = TFT_eSPI(); //inicializace displeje
RTC_DS3231 rtc; //inicializace RTC

// Externí RTC objekt 
extern RTC_DS3231 rtc;

// TADY JE DEFINICE VSECH PINU 
// [v20b] pause flags
bool protPaused = false;
long protPausedRemainMs = 0;
/*pro displej 4" 480*320
!!! Nastavení v souboru User_Setup.h :
#define ST7796_DRIVER
#define TFT_MISO 12
#define TFT_MOSI 13
#define TFT_SCLK 14
#define TFT_CS   15  // Chip select control pin
#define TFT_DC    27  // Data Command control pin
#define TFT_RST   -1  // RST connected to RST pin
*/

//proměnné pro SPI SD karty - SD karta je připojena na druhý SPI
#define REASSIGN_PINS
int sck = 18;
int miso = 19;
int mosi = 23;
int cs = 05;


//tlacitko enkoderu
#define ENC_KEY 4    // KEY tlačítko enkodéru
#define ENC_S1  39   // Enkodér pin A
#define ENC_S2  36   // Enkodér pin B

#define SDA 21   // definice pinu I2C sběrnice
#define SCL 22 

// tlacitka menu a enter
const int TL_Menu = 0;  //tlačítko Enter na GPIO0
const int TL_Enter = 17;  //tlačítko Enter na GPIO2


//proměnné pro práci s SD kartou
#define MAX_LATEK 20  // max 20 látek = 40 řádků (od 4 do 43)
String AktivniLatky[MAX_LATEK];
int aktivniCasy[MAX_LATEK];
int pocetLatek = 0; // počet skutečně načtených látek
// --- Pro výběr protokolu z SD karty ---
String seznamProtokolu[20];   // max 20 protokolů (lze zvětšit)
int pocetProtokolu = 0;
int aktivniVolba = 0;         // index označeného řádku
bool rezimVyberu = false;     // jsme ve výběru souboru?

//define some colour values
#define  BLACK   0x0000
#define BLUE    0x001F
#define RED     0xF800
#define GREEN   0x07E0 
#define CYAN    0x07FF
#define MAGENTA 0xF81F
#define YELLOW  0xFFE0
#define WHITE   0xFFFF
#define BARVA_RAMU       tft.color565(43, 165, 200)     // tmavší cyan
#define BARVA_ZALOZKY_T  tft.color565(0, 65, 130)       // tmavá modrá
#define BARVA_ZALOZKY_S  tft.color565(0, 102, 204)      // střední modrá
#define BARVA_ZALOZKY_PT tft.color565(0, 101, 202)      // tmavý popis záložky
#define BARVA_ZALOZKY_PS tft.color565(204, 230, 255)    // světlý popis záložky
#define BARVA_VYPISU     tft.color565(230, 242, 255)    // pozadí výpisu

//proměnné pro záložky
int aktivnizalozka = 0;  // aktuální záložka
const int pocetZalozek = 5;
uint8_t Podtrzitko = 0;     //proměná pro vykreslování podtržítka během nastavování
int fillScrollOffset = 0;


// Stav programu 0: IDLE, 1: WAIT_START, 2: RUNNING
volatile int programState = 0; // 
bool statGreenBox = false;     // po 1. ENTER ukázat zelené okno

/*** [v19e] Countdown state (STAT line) ***/
int  statCountX = 0, statCountY = 0;
int  statCountdown = -1;
int  statCountdownPrev = -1;
bool statCountdownActive = false;
bool dwnPrev = false;
bool protocolActive = false;   // běží interpret protokolu
int  protLine = 4;             // začínáme od dvojice 4/5
int  protPhase = 0;            // 0: načti pár, 1: DWN, 2: čekám, 3: UP
unsigned long protUntil = 0;   // millis do kterého čekáme
bool protFirstPair = true;     // první dvojice bez posunu karuselu
String statStatusWord = "";    // zobrazené slovo vedle "Status:"
int    statStatusSecs = -1;    // zobrazený počet sekund

//proměnné pro debounce tlačítek a encodéru
unsigned long lastEncoderEvent = 0;
const unsigned long encoderDebounceDelay = 300;  // debounce 300 ms

// Proměnné pro čas
DateTime now;
char cas[9];   // "HH:MM:SS"
char datum[11]; // "DD.MM.YYYY"
unsigned long lastRTCUpdate = 0;
const unsigned long rtcUpdateInterval = 1000; // 1 sekunda
bool nastavCas = false;        // režim nastavování hodin
int hodin = 11;
int minut = 22;
int den = 33;
int mesic = 44;
int rok = 55555;

//proměnné pro provoz
bool konam = false; //hlavní semafor ukazující, že se provádí operace (chod hlavního motoru)

// definice a přerušení tlačítek
volatile bool menuButtonInterruptFlag = false;
volatile bool enterButtonInterruptFlag = false; // proměnné pro debounce
unsigned long lastEncoderEvent3 = 0;
unsigned long lastDebounceTime = 0;
const unsigned long debounceDelay = 300;  // 300 ms debounce

// ISR – přerušení na tlačítko MENU
void IRAM_ATTR menuButtonISR() {
  if (millis() - lastEncoderEvent3 > encoderDebounceDelay) {
    lastEncoderEvent3 = millis(); // aktualizace času
    menuButtonInterruptFlag = true;
  }
}

// ISR – přerušení na tlačítko ENTER
void IRAM_ATTR enterButtonISR() {
  if (millis() - lastEncoderEvent3 > encoderDebounceDelay) {
    lastEncoderEvent3 = millis();
    enterButtonInterruptFlag = true;
  }
}


//proměnné a přerušení encodéru
volatile bool keyPressed = false;
bool encLastState = HIGH;
bool encCW = false;
bool encCCW = false;
int progScrollOffset = 0;   // Posun výpisu na kartě PROG (0 až 4)

void IRAM_ATTR ENC_key_ISR() { // zvlášť ošetřené zákmity tlačítka enkodéru
  if (millis() - lastEncoderEvent > encoderDebounceDelay) {
    keyPressed = true;
  }
}

// funkce SD karty
void listDir(fs::FS &fs, const char *dirname, uint8_t levels) {
  Serial.printf("Listing directory: %s\n", dirname);

  File root = fs.open(dirname);
  if (!root) {
    Serial.println("Failed to open directory");
    return;
  }
  if (!root.isDirectory()) {
    Serial.println("Not a directory");
    return;
  }

  File file = root.openNextFile();
  while (file) {
    if (file.isDirectory()) {
      Serial.print("  DIR : ");
      Serial.println(file.name());
      if (levels) {
        listDir(fs, file.path(), levels - 1);
      }
    } else {
      Serial.print("  FILE: ");
      Serial.print(file.name());
      Serial.print("  SIZE: ");
      Serial.println(file.size());
    }
    file = root.openNextFile();
  }
}

// nalezení souboru s aktivním protokolem v config.txt
String AktivniProtokol() {
  File configFile = SD.open("/config.txt");
  String aktivniprotokol = "";

  if (!configFile) {
    Serial.println("Nepodařilo se otevřít config.txt");
    return "";
  }

  int radek = 0;
  while (configFile.available()) {
    String line = configFile.readStringUntil('\n');
    radek++;

    if (radek == 4) {
      aktivniprotokol = line;
      break;
    }
  }

  configFile.close();

  // Oříznutí případného \r nebo mezery na konci
  aktivniprotokol.trim();

  Serial.print("Aktivní protokol: ");
  Serial.println(aktivniprotokol);
  return aktivniprotokol;
}
// konec aktivního protokolu

// načtení údajů z aktivního protokolu do polí
void NactiProtokol() {
  String jmenoSouboru = AktivniProtokol();
  File soubor = SD.open("/" + jmenoSouboru);
  if (!soubor) {
    Serial.print("Nelze otevřít aktivní protokol");
    Serial.println(jmenoSouboru);
    return;
  }

  int radek = 0;
  int index = 0;

  while (soubor.available() && radek < 43) {
    String line = soubor.readStringUntil('\n');
    radek++;

    // Od 4. řádku dál
    if (radek >= 4 && radek <= 43) {
      line.trim();  // odstraní \r, \n a mezery

      // Sudé řádky: látky (4,6,42)
      if (radek % 2 == 0) {
        if (index < MAX_LATEK) {
          AktivniLatky[index] = line;
        }
      }
      // Liché řádky za nimi: časy (5,7,43)
      else {
        if (index < MAX_LATEK) {
          aktivniCasy[index] = line.toInt();
          index++;
        }
      }
    }

  }

  soubor.close();
  pocetLatek = index;
  LogEvent("Protocol read");
}
// konec načítání aktivního protokolu do polí

//funkce pro výběr aktivního protokolu z SD karty
void NactiSeznamProtokolu() {
  File root = SD.open("/");
  pocetProtokolu = 0;

  while (true) {
    File entry = root.openNextFile();
    if (!entry) break;
    String name = entry.name();

    if (name.startsWith("proto") && !entry.isDirectory()) {
      seznamProtokolu[pocetProtokolu++] = name;
      if (pocetProtokolu >= 20) break; // bezpečnostní limit
    }

    entry.close();
  }
  root.close();
}


// Pomocná funkce: zapiš čas a hlášku do log.txt
void LogEvent(const char* message) {
  DateTime now = rtc.now();   // přečti aktuální čas z RTC

  // Otevři (nebo vytvoř) soubor log.txt v režimu přidávání
  File logFile = SD.open("/log.txt", FILE_APPEND);
  if (logFile) {
    // Sestav řádek: "YYYY-MM-DD HH:MM:SS - hláška"
    logFile.print(now.year());
    logFile.print("-");
    if (now.month() < 10) logFile.print('0');
    logFile.print(now.month());
    logFile.print("-");
    if (now.day() < 10) logFile.print('0');
    logFile.print(now.day());
    logFile.print(" ");

    if (now.hour() < 10) logFile.print('0');
    logFile.print(now.hour());
    logFile.print(":");
    if (now.minute() < 10) logFile.print('0');
    logFile.print(now.minute());
    logFile.print(":");
    if (now.second() < 10) logFile.print('0');
    logFile.print(now.second());

    logFile.print(" - ");
    logFile.println(message);
    logFile.close();
  } else {
    Serial.println("Nelze otevřít log.txt pro zápis!");
  }
}
// [v20_log] --- konec funkce ---

void kresliVyberProtokolu() {
  tft.fillRect(7, 81, 306, 392, BARVA_RAMU);
  tft.setTextColor(BARVA_ZALOZKY_PS, BARVA_RAMU);
  tft.setTextSize(2);
  tft.setTextDatum(TL_DATUM);

  int xLeft = 17;
  int yBase = 100;
  int lineHeight = 22;

  tft.drawString("Protocol:", xLeft, yBase - 5);
  tft.drawString(AktivniProtokol(), xLeft + 110, yBase - 5);

  for (int i = 0; i < pocetProtokolu; i++) {
    int y = yBase + (i + 1) * lineHeight;
    tft.drawString(seznamProtokolu[i], xLeft + 20, y);

    // Podtržítko pod aktuální volbou
    if (i == aktivniVolba) {
      tft.drawLine(xLeft + 18, y + 20, xLeft + 18 + seznamProtokolu[i].length() * 11, y + 20, BARVA_ZALOZKY_PS);
    }
  }
}
//konec funkcí výběru protokolu



// === [v13] začátek doplnění z test_obou_motoru_06 ===
// "test obou motoru 06" – krokový motor (karusel) + DC motor (rameno) + víko
// zajištěno najití nulové polohy čidlem nulové polohy a dorovnáním o 100 kroků, což kompenzuje šířku výřezu čidla

#include <AccelStepper.h>                        // S4
#include <Wire.h>                                // D5
#include <Adafruit_PWMServoDriver.h>             // D5

// ====== TB6600 piny ======
const int DIR  = 32;                             // S4
const int STEP = 26;                             // S4
const int EN   = 25;                             // S4
const int EN_ACTIVE_LEVEL = HIGH;                // S4
const int EN_IDLE_LEVEL   = (EN_ACTIVE_LEVEL == HIGH) ? LOW : HIGH; // S4

// ====== krokování ======
const int  FULL_STEPS_PER_REV = 200*60/12;       // S4
const int  MICROSTEP_DIV      = 16;              // S4
const long STEPS_PER_REV      = (long)FULL_STEPS_PER_REV * MICROSTEP_DIV; // S4

// ====== rychlosti/akcelerace ======
const float NORM_MAX_SPEED   = 1000;             // M
const float NORM_ACCEL       = 30;               // M
const float SEEK_FAST_MAX    = 2200;             // M – rychlý běh vpřed
const float SEEK_FAST_ACCEL  = 120;              // M – rozjezd vpřed
const float SEEK_BRAKE_ACCEL = 2400;             // M – JEŠTĚ prudší brzdění (≈ poloviční překmit)
const float SEEK_SLOW_CONST  = 120;              // M – 2× rychlejší zpětný pomalý chod (bylo 60)
const int   ZERO_EXTRA_MICROSTEPS = 100;           // M – dofázování po návratu do LOW

AccelStepper motor(AccelStepper::DRIVER, STEP, DIR); // S4

// ====== PCA9685 / DC motor / víko ======
#define I2C_SDA    21                            // D5
#define I2C_SCL    22                            // D5
#define PCA_ADDR   0x40                          // D5
#define CH_ENA     0                             // D5
#define CH_IN1     1                             // D5
#define CH_IN2     2                             // D5
#define CH_VIKO    3                             // D5
#define PIN_LIMIT_UP   35                        // D5
#define PIN_LIMIT_DWN  34                        // D5
#define PIN_ZERO       33                        // M – nulová poloha (LOW)
#define PWM_FREQ_HZ    1000                      // D5
#define PWM_SPEED      2048                      // D5

Adafruit_PWMServoDriver pwm(PCA_ADDR);           // D5
unsigned long vikoUntil = 0;                     // D5
bool nextIsUp = true;                            // D5

// ====== util ======
void pcaWrite(uint8_t ch, bool high) { if (high) pwm.setPWM(ch,4096,0); else pwm.setPWM(ch,0,0); } // D5
inline bool upHit()   { return digitalRead(PIN_LIMIT_UP)  == LOW; }  // D5
inline bool dwnHit()  { return digitalRead(PIN_LIMIT_DWN) == LOW; }  // D5
inline bool zeroHit() { return digitalRead(PIN_ZERO)       == LOW; } // M
void Viko_UP()  { Serial.println("Viko"); pcaWrite(CH_VIKO,true);  vikoUntil = millis()+4000; } // D5
void Viko_DWN() { Serial.println("Viko"); pcaWrite(CH_VIKO,false); }                           // D5
void Motor_STOP(){ pwm.setPWM(CH_ENA,0,0); pcaWrite(CH_IN1,false); pcaWrite(CH_IN2,false); pcaWrite(CH_VIKO,false); vikoUntil=0; Serial.println("Motor STOP"); } // D5
void STOP_UP()  { if (upHit())  { Serial.println("stisk UP");  Motor_STOP(); nextIsUp=false; } } // D5
void STOP_DWN() { if (dwnHit()) { Serial.println("stisk DWN"); Motor_STOP(); nextIsUp=true;  } } // D5

void Motor_UP(){                                    // D5
  if (upHit()) { STOP_UP(); return; }
  pcaWrite(CH_IN1,true); pcaWrite(CH_IN2,false);
  pwm.setPWM(CH_ENA,0,PWM_SPEED);
  Serial.print("Motor "); Serial.println(PWM_SPEED);
  while (!upHit()) { if (vikoUntil && millis()>=vikoUntil){ pcaWrite(CH_VIKO,false); vikoUntil=0; } delay(2); }
  STOP_UP();
  LogEvent("Arm UP");
}
void Motor_DWN(){                                   // D5
  if (dwnHit()) { STOP_DWN(); return; }
  pcaWrite(CH_IN1,false); pcaWrite(CH_IN2,true);
  pwm.setPWM(CH_ENA,0,PWM_SPEED);
  Serial.print("Motor "); Serial.println(PWM_SPEED);
  while (!dwnHit()) { if (vikoUntil && millis()>=vikoUntil){ pcaWrite(CH_VIKO,false); vikoUntil=0; } delay(2); }
  STOP_DWN();
  LogEvent("Arm DWN");
}
// [v19c] --- Neblokující řízení DC motoru ramene (pouze pro interpret protokolu) ---
int nbMotorState = 0; // 0=idle, 1=UP, 2=DWN

inline void Motor_UP_nb_start(){
  if (upHit()) { STOP_UP(); nbMotorState = 0; return; }
  pcaWrite(CH_IN1,true); pcaWrite(CH_IN2,false);
  pwm.setPWM(CH_ENA,0,PWM_SPEED);
  nbMotorState = 1;
      LogEvent("Motor UP");
}

inline void Motor_DWN_nb_start(){
  if (dwnHit()) { STOP_DWN(); nbMotorState = 0; return; }
  pcaWrite(CH_IN1,false); pcaWrite(CH_IN2,true);
  pwm.setPWM(CH_ENA,0,PWM_SPEED);
  nbMotorState = 2;
      LogEvent("Motor DWN");
}

inline bool Motor_nb_tick(){
  if (nbMotorState == 1){
    if (upHit()){ STOP_UP(); nbMotorState = 0; return true; }
    return false;
  } else if (nbMotorState == 2){
    if (dwnHit()){ STOP_DWN(); nbMotorState = 0; return true; }
    return false;
  }
  return true; // idle -> hotovo
}


// ====== rychlé nulování: FAST vpřed + prudké brzdění + SLOW zpět + dofázování 4 mikrokroky ======
void ZeroPositionFast(){                           // M – samostatná procedura
  Serial.println("nulova pozice karuselu");        // M

  // víko UP + 250 ms
  Viko_UP(); unsigned long t0 = millis(); while (millis()-t0 < 250) { yield(); } // M

  // FAST vpřed – kontinuálně
  motor.setMaxSpeed(SEEK_FAST_MAX);                // M
  motor.setAcceleration(SEEK_FAST_ACCEL);          // M
  digitalWrite(EN, EN_ACTIVE_LEVEL);               // S4
  const long Z_FWD_FAR = STEPS_PER_REV * 50L;     // M
  motor.moveTo(motor.currentPosition() + Z_FWD_FAR);
  while (true){
    motor.run();
    if (zeroHit()){                                // první LOW → prudká brzda
      motor.setAcceleration(SEEK_BRAKE_ACCEL);     // M – rychlejší zastavení
      motor.stop();
      break;
    }
    if (motor.distanceToGo()==0){                  // pojistka
      motor.setAcceleration(SEEK_BRAKE_ACCEL);
      motor.stop();
      break;
    }
  }
  while (motor.run()) {}                           // doběh do 0 rychlosti

  // SLOW zpět – KONSTANTNÍ rychlost, 2× rychlejší než předtím
  motor.setSpeed(-SEEK_SLOW_CONST);                // M (runSpeed bez ramp)
  // Nejprve opusť okno (LOW→HIGH), aby další LOW byla hrana:
  while ( zeroHit() ){ motor.runSpeed(); yield(); }
  // Hledej opětovný nájezd do LOW:
  while (!zeroHit() ){ motor.runSpeed(); yield(); }
  
  // LOW dosaženo – DOFÁZUJ ješte kousek:
  motor.setMinPulseWidth(3); motor.setMaxSpeed(NORM_MAX_SPEED); motor.setAcceleration(NORM_ACCEL);
  motor.runToNewPosition(motor.currentPosition() - (ZERO_EXTRA_MICROSTEPS)); 

  // nastav nulu + víko DOLŮ + EN vypnout + návrat rychlostí
  motor.setCurrentPosition(0);                      // M ★ nula
  Viko_DWN();                                       // D5
  t0 = millis(); while (millis()-t0 < 250) { yield(); } // M
  digitalWrite(EN, EN_IDLE_LEVEL);                  // S4
  motor.setMaxSpeed(NORM_MAX_SPEED);                // M
  motor.setAcceleration(NORM_ACCEL);                // M
  LogEvent("Zero position set");
}

// Funkce provede posun karuselu o +1 pozici (STEPS_PER_REV/20) bezpečným způsobem.
void karusel_plus1(){
  Viko_UP(); 
  digitalWrite(EN, EN_ACTIVE_LEVEL);
  motor.runToNewPosition(motor.currentPosition() + (STEPS_PER_REV/20));
  digitalWrite(EN, EN_IDLE_LEVEL);
  Serial.println("Karusel: posun o jednu");
  LogEvent("Caroussel moved +1");
  Viko_DWN(); 
}
// [v19a] --- Neblokující řízení karuselu pouze pro interpret protokolu ---
bool protCarouselActive = false;
long protCarouselTarget = 0;

void protCarouselStartPlus1(){
  Viko_UP(); 
  long step = (STEPS_PER_REV/20);
  protCarouselTarget = motor.currentPosition() + step;
  digitalWrite(EN, EN_ACTIVE_LEVEL);
  motor.moveTo(protCarouselTarget);
  protCarouselActive = true;
  Serial.println("[v19a] Carousel start +1 (non-blocking)");
  LogEvent("Caroussel moved +1");
  Viko_DWN(); 
}

bool protCarouselTick(){
  Viko_UP(); 
  if (!protCarouselActive) return true;
  motor.run();
  if (motor.distanceToGo() == 0){
    digitalWrite(EN, EN_IDLE_LEVEL);
    protCarouselActive = false;
    Serial.println("[v19a] Carousel reached target");
    return true;
  }
  return false;
   Viko_DWN(); 

}


void karusel_minus1(){
  Viko_UP(); 
  digitalWrite(EN, EN_ACTIVE_LEVEL);
  motor.runToNewPosition(motor.currentPosition() - (STEPS_PER_REV/20));
  digitalWrite(EN, EN_IDLE_LEVEL);
  Serial.println("Karusel: posun o jednu");
  LogEvent("Caroussel moved -1");
  Viko_DWN(); 
}




///////////////////////////////////////////////////////////////////////////////////////////////////////////////////////////////////////////////////////////////////////////

#include <Arduino.h>

#include <BLEDevice.h>
#include <BLEServer.h>
#include <BLEUtils.h>
#include <BLE2902.h>
#include <BLE2901.h>

String WIFI_SSID = "";
String WIFI_PASSWORD = "";

String SMTP_HOST = "";
uint SMTP_PORT = 0;

String SENDER_EMAIL = "";
String SENDER_PASSWORD = "";

String RECIPIENT_EMAIL = "";

bool shouldSendEmail = false;

const String DEVICE_BT_NAME = "TP Control";
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
void loop() {
  
  zpracujEnkoder();  // obsluha enkodéru

  // Zpracování stisku tlačítka menu s odrušením
  if (menuButtonInterruptFlag) {
    unsigned long currentTime = millis();
    if (currentTime - lastDebounceTime > debounceDelay) {
      lastDebounceTime = currentTime;

      aktivnizalozka = (aktivnizalozka + 1) % pocetZalozek;
      kreslizalozku();

      switch (aktivnizalozka) {
        case 0: kresliSTAT(); break;
        case 1: kresliRUN();  break;
        case 2: kresliPROG(); break;
        case 3: kresliFILL(); break;
        case 4: kresliSET();  break;
      }
    }
    menuButtonInterruptFlag = false;  // vlajku resetuj vždy až po vyhodnocení
  }

  zpracujEnter(); //obsluha tlačítka Enter
  ProtocolTick();
  ProtocolTick();

  // Aktualizace hodin každou sekundu, pokud není v režimu nastavení
  if (!nastavCas && (millis() - lastRTCUpdate > rtcUpdateInterval)) {
    NactiTIME();
    PrepisTIME(); 
    lastRTCUpdate = millis();
  }




  //BLE---------------------------------------------------------------------
  unsigned long currentMillis = millis();
  if (deviceConnected) {
    // // pFileCharacteristic->setValue(message); //ořízne zprávu na 20 znaků...
    // // pFileCharacteristic->notify();
    // String rxValue = pFileCharacteristic->getValue();
    // Serial.println(rxValue);
    // if (rxValue == "Send email") {
    //   sendEmail();
    // }

    // String txValue = "Hello";
    // pFileCharacteristic->setValue(txValue);  //ořízne zprávu na 20 znaků...
    // Serial.println(txValue);

    if (receivingBtData || receivingBtName || receivingSettingsBtData) {
      if (currentMillis - lastBtCommReceivedInMillis >= btCommTimeout) {
        receivingBtData = false;
        receivingBtName = false;
        receivingSettingsBtData = false;
        Serial.println(F("Didn't received end of transmission in time. Throwing away incomplete file."));
      }
    }

    if (receivingBtDataEnded) {
      receivingBtData = false;
      receivingBtDataEnded = false;
      Serial.println(receivedFileData);
      //receivedFileData = "";
    }

    if (receivingBtNameEnded) {
      receivingBtName = false;
      receivingBtNameEnded = false;
      Serial.println(receivedFileName);
      //receivedFileName = "";
      writeProtocolFromBt();
    }

    if (receivingSettingsBtDataEnded) {
      receivingSettingsBtData = false;
      receivingSettingsBtDataEnded = false;
      Serial.println(receivedSettingsData);
      //receivedSettingsData = "";
      writeSettingsFromBt();
    }

    delay(50);
  }

  // disconnecting
  if (!deviceConnected && oldDeviceConnected) {
    delay(500);                   // give the bluetooth stack the chance to get things ready
    pServer->startAdvertising();  // restart advertising
    Serial.println(F("start advertising"));
    oldDeviceConnected = deviceConnected;
  }

  // connecting
  if (deviceConnected && !oldDeviceConnected) {
    // do stuff here on connecting
    oldDeviceConnected = deviceConnected;
  }
  //END BLE---------------------------------------------------------------------
}
